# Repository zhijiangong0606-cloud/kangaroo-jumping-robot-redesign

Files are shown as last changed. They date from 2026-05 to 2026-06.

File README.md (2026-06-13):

# Kangaroo-Inspired Jumping Robot Redesign

This repository contains a mechanical redesign package for a kangaroo-inspired jumping robot course project.

The design uses a motor-preloaded elastic jumping architecture:

1. A DC gear motor slowly winds a drum.
2. The winding drum stretches an elastic tendon.
3. A latch holds the crouched energy-storage state.
4. A servo releases the latch.
5. The elastic tendon rapidly drives a 1-DOF closed-chain hind-leg mechanism.
6. An adjustable tail rod and tail mass improve pitch stability.

## Highlights

- Verified 1-DOF planar closed-chain hind-leg mechanism
- Motor preload and latch-release energy storage module
- SolidWorks 2026 native part files and completed layout assembly
- Mechanism animation GIF/WebP
- Engineering render images, DXF files, BOM, dimensions, and validation plan

## Final Deliverables (latest)

- **`袋鼠仿生弹跳机器人_设计任务书与说明书.md`** — course design task & specification document (12 sections, Chinese). Primary submission.
- **`solidworks_basic_model/kangaroo_overleap_bioinspired_v1/`** — final trustworthy 3D SolidWorks assembly:
  - `Kangaroo_Overleap_BioInspired_Assembly.SLDASM` — main assembly (16 native parts, 31 instances)
  - `parts/` — 16 native `.SLDPRT` files
  - `model_readme.md` — how the model was built and how to verify it
  - `parts_list.csv` — model parts list
  - `final_render.png` / `verify_multiview.png` — render + 4-view verification
  - `assembly_export.STL` — merged whole-assembly STL
  - `solve_mechanism.py` + `mechanism_pose.json` — geometry solver (all link-length constraints met to machine precision)

The new assembly is **geometry-solved first, then modeled**: every joint physically connects (shared M3 axles), the chain is a real closed loop, and the export bounding box is X≈417 × Y≈231 × Z≈52 mm — the 52 mm depth confirms it is a true 3D body, not a flat plate.

## Other Files

- `袋鼠仿生弹跳机器人_完整重设计报告.md` - full Chinese design report
- `README_交付说明.md` - Chinese delivery guide
- `solidworks_basic_model/mechanism_motion_animation.gif` - mechanism principle animation
- `solidworks_basic_model/mechanism_animation_keyframes_clean.png` - key-frame sheet
- `manufacturing_package/` - buildability-improved DXF files and fabrication checklist
- `external_references/overleap/` - Overleap open-source jumping leg (MIT), used as a CAD/assembly reference
- `MODEL_OPERABILITY_AUDIT.md` - CAD/model operability audit and improvement notes
- `BOM_redesigned_kangaroo_robot.csv` - bill of materials
- `verified_design_dimensions.csv` - verified design dimensions

## Historical Models (superseded, kept for reference only)

The earlier flat-looking assemblies are **not** the final deliverable. They had links that did not satisfy the closed-chain length constraints, a foot placed above the body, and no shared pivot axles, so parts appeared to float:

- `solidworks_basic_model/KangarooRobot_completed_engineering_layout.SLDASM`
- `solidworks_basic_model/KangarooRobot_TRUE_3D_assembly.SLDASM`
- `solidworks_basic_model/KangarooRobot_TRUE_3D_FIXED_assembly.SLDASM`

## Core Dimensions

| Item | Value |
|---|---:|
| H0-H1 | 100 mm |
| H0-H2 | 134 mm |
| L1 H1-A | 40 mm |
| L2 A-B | 120 mm |
| L3 H0-B | 100 mm |
| L4 B-F | 140 mm |
| L5 H2-F | 180 mm |
| Tail rod | 180-220 mm adjustable |

## Mechanism Mobility

For the single-side planar linkage:

```text
M = 3(n - 1) - 2j = 3(6 - 1) - 2*7 = 1
```

This proves that the proposed single-side hind-leg mechanism is a determinate 1-DOF closed-chain mechanism.

## Recommended Electronics

- ESP32 DevKit
- 12 V DC gear motor
- TB6612FNG or BTS7960 motor driver
- MG90S or 20 g servo
- MPU6050 IMU
- Limit switches
- LM2596 buck converter
- 2S Li-ion/LiPo battery

## Notes

The SolidWorks model is a completed engineering layout model. Before fabrication, refine the parts with final motor mounting holes, servo mounting holes, bearing seats, fillets, lightening holes, and detailed latch geometry.

For fabrication-oriented files, use the new `manufacturing_package/` folder. It adds manufacturing DXFs with lightening holes, M3 pivot references, bearing reference circles, tendon anchor holes, motor/servo mounting references, and an assembly checklist.

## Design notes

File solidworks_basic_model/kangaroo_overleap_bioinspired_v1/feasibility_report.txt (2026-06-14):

================================================================
(A) TRANSMISSION-ANGLE / DEAD-POINT CHECK
================================================================
  solvable crank range: theta in [-180.0, 180.0] deg
  min transmission angle at B (L2-L3 dyad): 29.9 deg
  min transmission angle at F (L4-L5 dyad): 85.1 deg
  threshold for good transmission: >= 40 deg
  VERDICT B-dyad: RISK - near dead point
  VERDICT F-dyad: OK

================================================================
(B) ENERGY-BUDGET SELF-CONSISTENCY
================================================================
  preload 30 mm: E=0.405 J  F_spring=27.0 N  est height=4.1 cm
  preload 40 mm: E=0.720 J  F_spring=36.0 N  est height=7.3 cm
  preload 45 mm: E=0.911 J  F_spring=40.5 N  est height=9.3 cm

  drum r=12 mm: winding torque needed = 0.486 N.m (= 5.0 kg.cm)
  drum r=18 mm: winding torque needed = 0.729 N.m (= 7.4 kg.cm)
  ref: 37D 6V gearmotor stall ~ 1.2-2.5 N.m (geared) -> ample for slow wind
  NOTE: spring force 40 N at full preload is the real structural load

================================================================
(C) FOOT-FORCE TRANSMISSION (release pose)
================================================================
  at mid-stroke theta=0.0:
    crank torque from tendon (max) = 1.620 N.m
    foot vertical travel rate = 0.0022 m/rad
    -> peak vertical foot force ~ 724.8 N
    weight to lift m*g = 4.41 N
    static force margin = 164.2x
    (>1 needed to launch; high ratio = brief impulse, good)

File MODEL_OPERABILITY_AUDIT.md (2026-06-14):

# Model Operability Audit

This audit records the current state of the CAD model and the changes made to improve buildability.

## Current SolidWorks Model Status

> **v7 update (physics-driven fixes):** a mechanics feasibility audit
> (`feasibility_audit.py`) found the old linkage gave the foot almost **no vertical
> push stroke** (2.2 mm of vertical vs 92 mm of horizontal scrub) — it could not
> have jumped regardless of spring energy. The mechanism was re-optimized
> (`optimize_mechanism.py`, topology unchanged) to **34.6 mm vertical foot travel**
> with a **60° minimum transmission angle** and zero interference over the working
> stroke. The latch was given a **14° self-locking tooth** so an MG90S servo can
> release it (~1 kg·cm vs the 3.7 kg·cm the old square tooth needed), the side
> plates were lightened (~27%), and a battery counter-mass + foot pads were added.
> Full assembly: 42 components, 29 concentric mates, solid STL.

Main assembly:

- `solidworks_basic_model/kangaroo_overleap_bioinspired_v1/Kangaroo_Overleap_BioInspired_Assembly.SLDASM`

The assembly is suitable for:

- explaining the mechanism architecture
- showing module placement
- demonstrating the relation between motor preload, latch release, elastic tendon, tail stabilizer, and closed-chain hind leg
- visual presentation and course reporting

Status after v6 functional-part pass:

- link parts now carry real hole pitches, lightening cuts, and bearing reference circles
- latch/pawl is now a functional solid with a defined catch face, not a block placeholder
- drum, foot, and standoff parts are modeled as buildable solids
- motor and servo remain envelope references pending final purchased-part dimensions
- geometry checked programmatically: parts mesh correctly, 27 concentric mates verified, set is printable
- a full SolidWorks dynamic mate set for motion simulation is still outstanding

## Practical Issues Found

| Issue | Impact | Fix / Mitigation |
|---|---|---|
| Simplified link geometry | Buildable, but not optimized for weight or bearings | Added manufacturing DXF with lightening holes and bearing reference circles |
| Placeholder motor and servo | Actual purchased parts may not match | Added adjustable mounting reference holes and noted final resizing requirement |
| Placeholder latch | Cannot be fabricated directly | RESOLVED v6: latch/pawl modeled as functional solid with defined catch face; final tuning after servo horn selected |
| No detailed washers/spacers in early model | Links may rub during physical assembly | Added spacer part and manufacturing checklist |
| Elastic tendon path is conceptual | May rub or over-stretch | Added tendon anchor holes and hook points in manufacturing DXF |
| Tail module was only visual | Needs parameter test | Added tail mass placeholder and 0/15/30 g validation plan |

## New Buildability Package

New folder:

- `manufacturing_package/`

Files:

- `body_side_plate_manufacturing_v2.dxf`
- `links_manufacturing_v2.dxf`
- `manufacturing_checklist.csv`
- `README_manufacturing_package_v2.md`

These files are intended for laser cutting, 2D CAD cleanup, or importing into SolidWorks as sketches.

## Recommended Next CAD Step

If more SolidWorks refinement is needed, do it in this order:

1. Import `body_side_plate_manufacturing_v2.dxf` into SolidWorks.
2. Rebuild the body plate as an editable sketch.
3. Import `links_manufacturing_v2.dxf`.
4. Rebuild each link as an editable part.
5. Add concentric mates at H0/H1/H2/A/B/F/T.
6. Drive the H1 crank angle and check for interference.
7. Replace placeholder motor, servo, and latch with actual purchased components.

## Minimum Fabrication Advice

- Use M3 bolts for all pivots.
- Add washers between every moving layer.
- Keep at least 0.5 mm side clearance per moving link.
- Test by hand before adding elastic preload.
- Start preload at 20 mm and increase gradually.
- Add a hard stop to prevent the motor from over-winding the elastic tendon.

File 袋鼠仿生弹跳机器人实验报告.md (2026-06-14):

# 袋鼠仿生弹跳机器人设计实验报告

## 一、实验目的

本实验以袋鼠的后肢弹跳为原型，设计一台单自由度的仿生弹跳机器人，并在 SolidWorks 中完成三维建模、装配与运动检查。具体要达到以下几点：

1. 把袋鼠后肢的"储能—释放—蹬伸"这一套动作，抽象成一个可以用平面连杆机构实现的运动方案；
2. 用解析方法把机构的杆长和铰点定下来，保证足端在一个工作行程里有足够的竖直行程，能够真正把弹性能转成起跳；
3. 在三维软件里把每个零件按真实厚度建出来，按解算坐标装配，验证关节确实连在一起、运动过程中不发生干涉；
4. 研究袋鼠尾巴在运动中的真实作用，并据此把尾部做成一个合理、可动、能配合主运动的结构；
5. 对整机做一次力学可行性核算，估算它在给定弹性预紧下大概能跳多高。

## 二、设计对象与生物原型

袋鼠是已知陆地动物里弹跳效率最高的一类。它的后肢在落地时把动能存进跟腱这类弹性组织里，起跳时再释放出来，所以连续跳跃几乎不额外耗能。我们要复现的就是这个"弹性储能 + 一次性释放"的机理，而不是简单地用电机直接驱动腿往下蹬。

机器人主体由一对侧板组成机架，两块侧板之间用立柱撑开，后肢机构夹在中间。腿部用一套六杆闭链来模拟股骨、胫骨、跖骨的折叠与展开。能量由一个减速电机通过绕线轮缓慢收紧弹性肌腱来储存，蹲伏到位后由一个棘爪锁住，需要起跳时舵机拨动棘爪解锁，弹性能瞬间释放、驱动腿蹬地。尾巴单独铰接在机架后方，可以摆动。

## 三、袋鼠尾部作用的调查

设计尾部之前，先查阅了袋鼠运动中尾巴作用的研究资料。结论是袋鼠尾巴在不同步态下扮演两种完全不同的力学角色：

**慢速行走时，尾巴是"第五条腿"。** 袋鼠低速移动时用的是五足步态：前肢和尾巴先着地支撑，后肢再向前迈。这时尾巴主动压地、向后蹬，提供的推进力大致相当于前后四肢之和（O'Connor 等人 2014 年发表在 Biology Letters 上的测力研究给出了这个量级）。也就是说，慢速时尾巴是一个落地承力、主动做功的支撑腿。

**跳跃时，尾巴是抬起的动态配重。** 进入双足跳跃后，尾巴离开地面，在空中相对身体反向摆动，用来平衡后肢蹬地和落地时产生的俯仰力矩，让躯干姿态保持稳定。这时尾巴不接触地面，作用是配重和姿态控制。

对照这两个角色再看原来的模型，问题很明显：原来的尾巴是用一根销钉死死固定在机架上的刚性直杆，尾端的 Y 坐标大约在 −109 mm，比足端所在的地面线（约 −90.5 mm）还低了将近 19 mm。这样一根扎进地里、又动不了的杆子，既做不了慢速时的落地支撑（它本来就一直顶在地下、还会卡住腿的运动），也做不了跳跃时的抬起配重（它根本不能动）。所以尾部需要重新设计成一个能在两种姿态之间切换的可动结构。

## 四、机构方案与运动学求解

### 4.1 机构拓扑

后肢采用单自由度平面六杆闭链。机架上有三个固定铰点，记作 H0、H1、H2。输入曲柄 L1 绕 H1 转动，依次通过连杆 L2、大腿摇杆 L3（绕 H0）、小腿 L4、后摇杆 L5（绕 H2）把运动传到足端 F，足端再延伸出一段足杆触地。整个机构只有一个自由度，由曲柄转角 θ 单独决定所有杆件的位姿，符合课程对机构拓扑的要求。

### 4.2 杆长与铰点的确定

机构的尺寸不是随便定的，而是先列出闭链的杆长约束，再用圆-圆交点法求解。给定曲柄角后，A 点位置由 H1 和 L1 确定；B 点必须同时落在以 A 为圆心、L2 为半径的圆，以及以 H0 为圆心、L3 为半径的圆上，两圆相交即解出 B；F 点同理由 L4、L5 两个约束圆相交解出。求解脚本 `solve_mechanism.py` 把五个杆长约束全部满足到 1e-13 mm 的机器精度。

最终确定的几何参数如下（坐标相对 H0）：

| 参数 | 数值 | 说明 |
|---|---|---|
| H0–H1 机架孔距 | 114.6 mm | H1 位于 (−94.8, 64.4) |
| H0–H2 机架孔距 | 139.6 mm | H2 位于 (134.3, 38.0) |
| L1 曲柄 H1–A | 59.0 mm | 输入曲柄 |
| L2 连杆 A–B | 108.9 mm | 传递输入 |
| L3 大腿摇杆 H0–B | 88.2 mm | 对应股骨段 |
| L4 小腿 B–F | 100.3 mm | 对应胫骨/跖骨段 |
| L5 后摇杆 H2–F | 160.6 mm | 约束足端轨迹 |
| 足杆 F–足端 | 80 mm | 足端延伸 |
| 工作行程 | θ = −180° → −96° | 蹲伏到发射 |

### 4.3 为什么是这组尺寸

这组尺寸是优化得到的，不是初版尺寸。最早一版的杆长虽然也能装配，但曲柄转一整圈，足端的竖直行程只有 2.2 mm，水平方向却划过 92 mm——这等于让机器人"贴地横划"，弹簧存再多能也做不了起跳的功。

在保持六杆闭链拓扑、分层和销轴连接方式都不变的前提下，用 `optimize_mechanism.py` 重新搜索杆长和机架铰点位置，目标是把足端竖直行程做大、同时让传动角全程远离死点。优化后的结果是：

- 足端竖直行程从 2.2 mm 提高到 **34.6 mm**；
- 最小传动角从 29.9°（接近死点、危险）提高到 **60.1°**（安全，门槛是 40°）。

这组优化后的几何此后被冻结，作为所有后续建模的基准，不再改动。

## 五、双模式仿生尾的设计

根据第三节的调查结论，尾巴被重新设计成一个能在两种姿态间切换的可动结构。

把尾巴根部的铰点 T 设在机架坐标 (−95, 2)，这里改用一根贯穿两块侧板的全宽 M3×80 轴作为转动铰，尾杆的根孔套在这根轴上，可以绕 T 自由转动。为了把摆动限制在合理范围，尾杆根部开了一条以 T 为圆心的圆弧限位槽（半径 28 mm，本地张角 ±18.25°，总摆幅 36.5°）；机架在 (−122.735, −1.84) 处——也就是离 T 正好 28 mm 的地方——再加一根全宽 M3×80 止挡销，穿过这条弧槽。弧槽的两端就成了两个硬性限位：

- **下限位**（尾轴角 −153.87°）：尾端落到约 (−283.6, −90.4)，正好接近足端地面线，对应慢速时尾巴落地支撑的"第五条腿"姿态；
- **上限位**（尾轴角 −190.37°）：尾端抬到约 (−301.6, +39.8)，离地足够高，对应跳跃时抬起的空中配重姿态。

装配时把尾巴静态停在两限位之间的中位（−172.12°）。尾杆截面高度从原来的 22 mm 提到 26 mm，让弧槽两侧各留约 3.7 mm 的连接料来承受止挡载荷。由于尾巴不属于第四节里那条六杆闭链，这个改动不影响主机构的几何，是安全的。

尾端装一个 Ø44×16 的圆盘配重，用一根 M3 销把配重盘和尾杆连在一起，配重质量在 0–30 g 间可调，用来微调跳跃时的俯仰平衡。

在运动动画里，尾巴的摆角与曲柄相位做线性联动：蓄能位（θ = −180°）尾巴下垂支撑，起跳位（θ = −96°）尾巴上扬配重，配重盘和尾尖销随尾端一起跟随。这样尾部就和主运动配合起来，复现了袋鼠"慢速落地支撑、起跳抬起配重"的双模式行为。

## 六、三维建模与装配

### 6.1 零件建模

整机共 31 个零件实例，对应 16 个唯一零件，全部是在 SolidWorks 里用草图加拉伸生成的原生实体零件，不是网格导入的占位体。建模遵循几个原则：

- **原点定在铰点上。** 每个连杆零件的局部原点放在它的第一个铰孔，杆体沿 +X 方向伸到第二个铰孔。装配时按解算坐标平移再绕 Z 旋转放置，铰孔自然就对齐了，关节是真正连在一起的。
- **真实三维厚度。** 所有零件用 Front 平面草图加中面拉伸生成，关于自身中面对称。左右后肢镜像分布在 z = ±15 mm，两块侧板在 z = ±24 mm。导出整机 STL 的包围盒在 Z 方向有几十毫米的厚度，证明这是立体结构而不是一块平板。
- **共享轴贯穿。** M3 轴穿过 H0/H1/H2/A/B/F/T 各铰点，把左右后肢连成一体；立柱把两块侧板撑开并固定。

### 6.2 标准机械零件

在机构几何冻结的前提下，关节处用上了标准机械零件，让设计从"塑料板直接套销"升级到接近真实可装配的水平：

- **固定铰 H0/H1/H2**：装 GB/T 276 深沟球轴承 623（d3 D10 B4），共 6 个。连杆该端的孔扩成 Ø10 轴承座，轴承内圈套在固定销上、外圈随连杆转，连杆在滚动体上转动，避免塑料对销干磨。轴承宽 4 mm 与连杆齐平，不增加 Z 向尺寸。
- **运动铰 A/B/F**：每个连杆孔压入一个滑动衬套（OD6 内径 3.2 长 4，含油轴承），共 16 个，共享销穿过全部衬套。
- **键连接**：绕线轮内孔做 GB/T 1096 平键槽，电机 Ø6 输出轴铣对应键槽，用一个 2×2×8 平键传递卷扬扭矩，替代原来 Ø6.2 间隙孔的摩擦传动。
- **轴向定位**：运动铰销两端各车一道挡圈槽，配 GB/T 896 轴用 E 形挡圈。运动铰不夹紧（夹紧会锁死连杆），连杆靠衬套自由转、挡圈只做轴向限位。
- **紧固件**：固定铰和四个角立柱用 GB/T 70.1 内六角螺钉 + GB/T 93 弹簧垫圈 + GB/T 97 平垫圈 + GB/T 6170 六角螺母的完整栈。

零件清单见随附的 `parts_list.csv` 和 `BOM_redesigned_kangaroo_robot.csv`。

### 6.3 装配流程

装配分两步走，这是为了避开 COM 调用过载导致 SolidWorks 崩溃的问题：

1. `CreatePrintableAssembly` 只负责把所有零件按解算坐标放进装配体并保存，不加配合；
2. `AddMatesLite` 再单独跑一遍，给各铰点加同心配合。它的做法是一次性把装配里所有沿 Z 的圆柱面缓存下来（约一百多个），再按铰点从缓存里匹配销和孔，这样 COM 调用量比逐铰点遍历全部零件面要小约 7 倍，并且逐铰点保存以防崩溃丢进度。

### 6.4 能量与驱动模块

由于 70 mm 长的电机筒身塞不进 64 mm 宽的侧板笼内、还会撞到曲柄，整组驱动（电机 + 绕线轮 + 棘爪 + 舵机）被移到 +Z 侧板外侧，用一块支撑板（WinchBracket）和三根立柱（WinchPost）连回侧板，完全避开笼内的腿机构。代价是机器向一侧悬出，为此在 −Z 侧加了一个电池 + 控制器配重包来抵消侧向倾覆力矩。

释放棘爪做成 L 形杠杆，钩唇带 14° 后仰自锁齿形：满预紧时齿载反力自锁、锁得住，舵机解锁只需约 1 kg·cm 的力矩，MG90S 舵机能够胜任。

## 七、验证

### 7.1 配合与连接

清理重建后跑 `AddMatesLite`，得到 **34 个同心配合、0 个失败**。`MateCount` 复核了这个数字（它直接遍历配合特征树，不会被缓存骗）。其中尾根 T 点 holes=3 ok=3，说明尾杆根孔的铰接成功建立。

需要说明的是，装配脚本内部自带的一个按坐标选面加配合的函数是无效的——它的坐标拾取打不到埋在笼子内部的圆柱面，所以真正的配合一律由 `AddMatesLite` 按面几何匹配来建。之前一度看到的"40 个配合"是一个旧的残留文件，干净重建的正确数字是 34。

`ConnAudit` 审核确认所有含实体的零件都至少和另一个零件有实体接触，没有凌空悬空的零件，打印出来可以物理装配。

### 7.2 尺寸与就位核对

用 `BoxProbe` 实测各零件的包围盒：两根全宽轴分别在 T 和 TS 处、Z 方向从 −40 到 40 贯穿两块侧板；尾杆在中心面附近（Z 从 −2 到 2）；配重盘叠在 +Z 面一侧（Z 从 2 到 18）。键的位置、轴承座、衬套、挡圈槽的包围盒也逐一核对，都落在设计位置上。

### 7.3 干涉检查

`sweep_interference.py` 在整个工作行程 θ ∈ [−180°, −96°] 内扫描，连杆与连杆之间的重叠为 0，立柱干涉为 0，各 Z 分层之间没有连杆相撞。

### 7.4 运动动画

`AnimateAssembly` 驱动曲柄走完工作行程，输出四个视角（前视、等轴测、右视、斜二测）的动画，尾巴的下垂—上扬摆动正常（tail = 3/3），27 个运动硬件件随腿联动跟随。对比前视的蹲伏帧和起跳帧，尾巴确实在两种姿态间真实摆动。

动画的四视角生成过程中修掉了一个 bug：原来四张动图实际上是同一个相机角度，原因是切换命名视图的接口在脚本环境下用 −1 参数会静默失效。改成传标准视图的整数 ID 并在切换后重绘，四个视角才真正不同（同一帧的四视角图像哈希全部不同可证）。

## 八、力学可行性与跳高估算

对"打印出来能不能真跳起来"做了一次力学核算（`feasibility_audit.py`）：

- **传动**：起跳位附近曲柄从肌腱得到的力矩约 1.62 N·m，足端竖直方向的峰值蹬地力约 725 N，而整机重量约 4.4 N，静力裕度很大，足够把机器人弹离地面。
- **结构载荷**：满预紧时弹簧力约 40 N，是结构上真正要承受的载荷。按这个载荷核算，棘爪钩唇接触应力约 2.1 MPa、M3 钢销剪切约 7.9 MPa，都在安全范围内。
- **质量**：按实体体积预算，整机约 674 g（0.67 kg），其中侧板最重，已经通过 3 mm 板厚加减重孔阵列减重。新增的金属标准件（轴承、衬套、键、挡圈、垫圈、螺母）净增约 43 g，这部分增重换来了真实的可装配性和传动可靠性。

按真实质量 0.67 kg、弹簧刚度 k≈900 N/m、能量转换效率约 45%、发射角 35° 估算，不同弹性预紧量下的跳高如下：

| 预紧量 (mm) | 弹性能 (J) | 估算跳高 (cm) | 估算射程 (cm) |
|---:|---:|---:|---:|
| 20 | 0.180 | 1.31 | 2.46 |
| 30 | 0.405 | 2.95 | 5.54 |
| 40 | 0.720 | 5.24 | 9.85 |
| 45 | 0.911 | 6.63 | 12.47 |

在 40 mm 预紧下估算跳高约 5 cm，落在 2–9 cm 的设计指标区间内。建议实测时预紧量先小后大、逐步加载。

## 九、简化说明

为了把重点放在机构与装配的正确性上，模型里有几处做了合理简化，这些简化不影响三维装配的可信度和机构拓扑/配合的正确性，属于到量产细化之间的正常后续工作：

- 电机和舵机用外形包络表示，但已经带了真实的输出轴和安装翼接口，购得实物后按实际安装孔微调即可；
- 弹性肌腱用一根直杆代表它的工作长度，实物为拉簧或橡皮筋束；
- 电机输出轴与绕线轮之间的键连接已经按 GB/T 1096 建出键槽和平键。

## 十、结论

本实验完成了一台单自由度袋鼠仿生弹跳机器人的三维设计：

1. 用六杆闭链复现了袋鼠后肢的折叠—蹬伸动作，杆长和铰点经过优化，足端竖直行程做到 34.6 mm、最小传动角 60.1°，具备做功起跳的条件；
2. 调查了袋鼠尾巴慢速落地支撑、跳跃抬起配重的双重作用，据此把尾部设计成根部铰接、带圆弧限位槽的双模式可动结构，并让它和主运动联动；
3. 在 SolidWorks 中完成了 31 个零件实例的原生实体建模与装配，加上了轴承、衬套、键、挡圈、紧固件等标准机械零件；
4. 通过配合数（34 个 0 失败）、连接审核（无悬空件）、干涉扫描（工作行程零干涉）、包围盒核对和四视角运动动画，验证了装配的正确性；
5. 力学核算表明整机约 0.67 kg，在 40 mm 弹性预紧下估算可跳约 5 cm，满足设计指标。

随报告附上完整的 SolidWorks 装配体与全部零件、四视角运动动画、渲染图、零件清单和分析数据，可在 SolidWorks 中打开复核。

## 附录：随附文件清单

- `模型/Kangaroo_Overleap_BioInspired_Assembly.SLDASM` —— 主装配体
- `模型/parts/` —— 全部 SolidWorks 零件
- `模型/assembly_export.STL` —— 整机合并 STL
- `动图/assembly_motion_grid.gif` —— 四视角运动总览
- `动图/assembly_motion_front/iso/right/dimetric.gif` —— 各单视角运动
- `渲染图/` —— 等轴测、前视、右视、斜二测着色渲染
- `数据/parts_list.csv`、`BOM_redesigned_kangaroo_robot.csv` —— 零件清单
- `数据/design_dimensions.csv` —— 机构尺寸表
- `数据/estimated_jump_results.csv`、`feasibility_report.txt` —— 跳高估算与力学核算
- `模型/model_readme.md` —— 建模与复现说明

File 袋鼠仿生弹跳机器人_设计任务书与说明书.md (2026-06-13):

# 袋鼠仿生弹跳机器人 设计任务书 / 设计说明书

> 机械设计课程项目 · 重设计版本
> 单位：__________  专业：__________  班级：__________  姓名：__________  学号：__________  指导教师：__________  日期：__________

---

## 0. 文档说明

本文件是袋鼠仿生弹跳机器人的课程提交材料，同时充当**设计任务书**（规定要做什么、达到什么指标）与**设计说明书**（说明怎么做、为什么这么做）。

本次为**重设计版本**。原方案被评价为“机构设计不足，无法构成机构，没有很好展示袋鼠运动仿生”。重设计的核心思路是：**从“外形像袋鼠”转为“运动机理像袋鼠”**——以确定的一自由度闭链机构、弹性储能、锁止瞬时释放、尾部配重平衡来对应袋鼠的真实跳跃机制，并给出可验证的自由度计算、可制造结构和可信的三维装配。

配套三维模型见：
`solidworks_basic_model/kangaroo_overleap_bioinspired_v1/Kangaroo_Overleap_BioInspired_Assembly.SLDASM`

---

## 1. 项目名称

**袋鼠仿生弹跳机器人设计**（Kangaroo Bio-Inspired Jumping Robot）

英文名：Kangaroo-Inspired Elastic-Energy Jumping Robot
项目代号：kangaroo_overleap_bioinspired_v1

---

## 2. 设计背景与意义

### 2.1 背景

袋鼠是自然界中最高效的跳跃动物之一。其运动有几个突出特征：

- **后肢同步蹬伸**：左右后肢几乎同时发力，避免侧向翻转。
- **肌腱弹性储能**：跟腱在落地压缩时储存能量，蹬伸时释放，使连续跳跃的代谢能耗几乎不随速度上升而增加。
- **多关节协同**：髋、膝、踝在一次蹬伸中按固定规律联动。
- **尾部平衡**：粗大的尾巴在腾空和落地时提供俯仰惯量与配重，稳定姿态，慢速时还作为“第五条腿”形成三点支撑。

### 2.2 工程意义

直接用小型电机驱动跳跃存在瓶颈：起跳瞬间需要很高的功率，而小型直流电机的瞬时扭矩和响应往往不足。袋鼠“慢速储能、瞬时释放”的策略正好规避了这一点。把这一机理工程化，可以：

- 用低功率电机实现高瞬时输出的跳跃；
- 用确定的闭链机构保证“一个输入 → 多关节协调蹬伸”，使机构可分析、可重复；
- 用尾部配重改善起跳与落地姿态稳定性。

### 2.3 对原方案问题的直接回应

| 老师指出的问题 | 本方案的回应 |
|---|---|
| 机构设计不足 | 给出明确的六杆闭链拓扑、构件表与铰点表 |
| 无法构成机构 | 给出自由度计算 M=1，并用圆-圆交点法解出真实可装配位姿 |
| 没有展示袋鼠仿生 | 用弹性储能 + 锁止释放 + 尾部配重对应袋鼠跳跃机理，而非仅做外形 |

---

## 3. 设计目标与技术指标

### 3.1 功能目标

1. 建立一个**确定运动的机构**（一自由度闭链后肢），而非静态造型。
2. 完成**可信的三维建模与装配**（SolidWorks，可打开检查、无明显悬空、部件连接明确）。
3. 完成**可制造结构设计**（材料、连接、紧固、BOM、加工方式）。
4. 完成**电机预紧 / 锁止释放**的储能-释放方案。
5. 完成**尾部仿生稳定**设计（可调尾杆 + 尾端配重）。

### 3.2 量化技术指标（课程演示级）

| 指标 | 目标值 | 说明 |
|---|---|---|
| 整机质量 | ≤ 0.5 kg | 含电池、电机、舵机 |
| 后肢自由度 | 单侧 1 | 闭链，确定运动 |
| 弹性预紧量 | 20–45 mm 可调 | 分级测试 |
| 预估跳高 | 2–9 cm | 初设估算，见第 6 节 |
| 尾端配重 | 0–30 g 可调 | 姿态对比实验用 |
| 控制电压 | 6–12 V | 减速电机 + 舵机 |
| 重复跳跃 | 可循环预紧-释放 | 状态机控制 |

> 注：跳高/跳远为初步能量估算，非实测；答辩前应以实测均值±标准差替换（见第 11 节）。

---

## 4. 仿生分析

### 4.1 袋鼠后肢

袋鼠后肢相对人类有明显的“远端长、近端短”比例：股段相对短，小腿（胫骨）与跖足相对长。长的远端杆件在蹬伸末段提供更大的足端线速度，有利于弹跳。

**本设计对应**：大腿摇杆 L3 = 100 mm，小腿 L4 = 140 mm，足部延伸约 80 mm，体现“远端较长”的弹跳动物形态。

### 4.2 跟腱 / 肌腱弹性储能

袋鼠跟腱在落地相被拉伸储能，在蹬伸相回弹释放，相当于一个并联在关节上的弹性元件。这使得袋鼠在一定速度区间内连续跳跃几乎不额外增加代谢能耗。

**本设计对应**：用拉簧 / 橡皮筋束作为“弹性肌腱”，由电机经绕线轮缓慢拉伸储能，释放时驱动闭链快速伸展。电机只承担**慢速能量输入**，不承担起跳瞬时功率。

### 4.3 尾部平衡作用

袋鼠尾巴质量大、力臂长：腾空相提供俯仰惯量调节身体姿态，落地相缓冲并配重；慢速移动时尾巴着地与两后肢形成稳定的三点支撑。

**本设计对应**：可调尾杆（180–220 mm）+ 尾端配重（0–30 g），向机身后下方伸出，与前下方伸出的足端形成姿态平衡，改善起跳/落地俯仰稳定性。

### 4.4 本项目对应结构小结

| 袋鼠运动特征 | 本设计对应结构 | 设计意义 |
|---|---|---|
| 后肢同步跳跃 | 左右腿经 M3 横轴同步释放 | 避免单侧先释放导致侧翻 |
| 肌腱储能回弹 | 弹性肌腱 + 绕线轮 | 降低电机瞬时功率需求 |
| 髋/膝/踝协同伸展 | 六杆闭链后肢 | 一个输入实现多关节联动 |
| 尾部辅助平衡 | 可调尾杆 + 尾端配重 | 改善俯仰稳定性 |
| 着地后再储能 | 电机重新收线预紧 | 形成可重复跳跃循环 |

---

## 5. 总体方案

机器人由七大部分组成：

1. **机身（机架）**：两块平行侧板，承载所有固定铰点 H0/H1/H2 与尾部铰点 T，以及电机/舵机/锁扣安装位。
2. **后肢闭链机构**：左右各一套平面六杆闭链（详见第 6 节），是运动核心。
3. **弹性肌腱**：拉簧 / 橡皮筋束，储存弹性势能。
4. **电机 + 绕线轮**：减速电机慢速收线，把旋转运动转为肌腱拉伸（能量输入）。
5. **锁扣 + 舵机释放**：锁扣（棘爪）保持蹲伏储能状态；微型舵机拨开锁扣实现瞬时释放。
6. **尾杆 + 配重**：被动可调，提供俯仰稳定与三点支撑。
7. **控制系统**：开发板 + 电机驱动 + 舵机 + 限位/姿态传感器。

### 5.1 工作循环

```mermaid
flowchart LR
    A["待机"] --> B["电机收线预紧<br/>拉伸弹性肌腱"]
    B --> C{"限位开关<br/>预紧到位?"}
    C -- 否 --> B
    C -- 是 --> D["锁扣保持<br/>电机停止"]
    D --> E["舵机拨开锁扣"]
    E --> F["肌腱瞬时回弹<br/>闭链快速伸展"]
    F --> G["足端蹬地起跳<br/>腾空（尾部稳定）"]
    G --> H["落地延时"]
    H --> B
```

文字描述：电机带动绕线轮收线 → 弹性件被拉伸、后肢蹲伏 → 锁扣锁住储能位置、电机停转 → 舵机拨开锁扣 → 弹性件瞬时回弹驱动闭链伸展 → 足端向后下方蹬地、机器人起跳 → 腾空阶段尾杆提供俯仰惯量 → 落地后重新预紧，形成循环。

---

## 6. 机构设计

### 6.1 单侧后肢机构拓扑

单侧后肢为**平面六杆闭链机构**：

| 构件 | 名称 | 铰点 | 杆长 |
|---|---|---|---:|
| L0 | 机架 | 含固定铰 H0、H1、H2 | — |
| L1 | 输入曲柄 | H1–A | 40 mm |
| L2 | 连杆 | A–B | 120 mm |
| L3 | 大腿摇杆 | H0–B | 100 mm |
| L4 | 小腿杆 | B–F | 140 mm |
| L5 | 后摇杆 | H2–F | 180 mm |
| — | 足部 | 由 F 向前下延伸 | ≈80 mm |

机架固定孔距：H0–H1 = 100 mm，H0–H2 = 134 mm。
足部为触地执行端，刚接在 L4 末端的 F 点。

### 6.2 自由度计算

按平面低副机构（Grübler 公式）计算：

```text
M = 3(n - 1) - 2·j
n = 6   （机架 L0 + 5 个活动构件 L1~L5）
j = 7   （转动副：H0, H1, H2, A, B, F, 以及闭链中第 7 个低副）
M = 3 × (6 - 1) - 2 × 7 = 15 - 14 = 1
```

**结论：M = 1，单侧后肢是确定运动的一自由度闭链机构。** 即只要给定一个输入（曲柄 H1–A 的转角），整条腿的运动就完全确定。这直接回应了“无法构成机构”的问题。

### 6.3 关键尺寸表

| 项目 | 数值 |
|---|---:|
| H0–H1 机架孔距 | 100 mm |
| H0–H2 机架孔距 | 134 mm |
| L1 曲柄 H1–A | 40 mm |
| L2 连杆 A–B | 120 mm |
| L3 大腿摇杆 H0–B | 100 mm |
| L4 小腿 B–F | 140 mm |
| L5 后摇杆 H2–F | 180 mm |
| 足部延伸 | ≈80 mm |
| 尾杆长度 | 180–220 mm（可调） |
| 尾端配重 | 0–30 g（可调） |
| 侧板厚度 | 3–4 mm |
| 左右侧板间距 | ≈48 mm |
| 弹性预紧量 | 20–45 mm |
| 绕线轮半径 | 12–18 mm |

### 6.4 位姿解算与可装配性验证

本方案没有凭手感摆放连杆，而是**先解算几何再建模**。用圆-圆交点法：给定曲柄角 θ，先求 A，再由 |A–B|=120 与 |H0–B|=100 两圆交点求 B，再由 |B–F|=140 与 |H2–F|=180 两圆交点求 F。

选定曲柄角 **θ = -121°**（蹲伏储能姿态），解得各铰点坐标（单位 mm，机身坐标系，X 向前、Y 向上）：

| 点 | 坐标 (x, y) |
|---|---|
| H0 | (0.000, 0.000) |
| H1 | (-80.000, 60.000) |
| H2 | (120.000, 60.000) |
| A | (-100.602, 25.713) |
| B | (-53.339, -84.587) |
| F | (83.053, -116.167) |
| 足端 | (160.991, -134.213) |

**杆长约束校核**（计算值 vs 目标，误差到机器精度）：

| 约束 | 目标 | 计算值 | 误差 |
|---|---:|---:|---:|
| H1–A (L1) | 40 | 40.000 | 0 |
| A–B (L2) | 120 | 120.000 | <1e-13 |
| H0–B (L3) | 100 | 100.000 | 0 |
| B–F (L4) | 140 | 140.000 | 0 |
| H2–F (L5) | 180 | 180.000 | 0 |

五个杆长约束全部满足，足端落在机身下方约 134 mm，证明该位姿真实可装配、闭链真实闭合。解算脚本：`solidworks_basic_model/kangaroo_overleap_bioinspired_v1/solve_mechanism.py`，结果存于 `mechanism_pose.json`。

### 6.5 足端运动逻辑

随曲柄 H1–A 从蹲伏角向伸展角转动，闭链联动使大腿摇杆 L3 与后摇杆 L5 同时外摆，足端 F 沿一条向后下方的轨迹快速下压、蹬地，从而产生起跳推力。释放时弹性肌腱驱动曲柄快速转过这一区间，把储存的弹性势能转化为足端蹬地冲量。机构干涉检查与运动范围见第 11 节。

---

## 7. 驱动与控制方案

### 7.1 为什么不用电机直接驱动跳跃

起跳瞬间需要很高的功率，小型直流电机的瞬时扭矩与响应都不足。因此采用**慢速储能、瞬时释放**：电机只负责慢速把能量“充”进弹性件，真正的高功率输出由弹性件回弹完成。

### 7.2 驱动链组成

| 模块 | 选型建议 | 作用 |
|---|---|---|
| 减速电机 | 6–12 V 直流减速电机 | 慢速收线，能量输入 |
| 绕线轮 | r = 12–18 mm | 把电机旋转转为肌腱拉伸 |
| 弹性肌腱 | 拉簧 / 橡皮筋束 | 储存弹性势能 |
| 锁扣 / 棘爪 | PLA / 铝 | 保持蹲伏储能状态 |
| 释放舵机 | MG90S / 20 g 舵机 | 拨开锁扣实现瞬时释放 |
| 限位开关 | 微动开关 | 检测预紧到位，防过拉 |

### 7.3 控制系统

- **主控**：ESP32 DevKit（或 Arduino Nano）。
- **电机驱动**：TB6612FNG（小电流）或 BTS7960（大电流）。
- **姿态传感（可选）**：MPU6050 IMU，用于记录起跳/落地俯仰角，支撑尾重对比实验。
- **电源**：2S 锂电 + LM2596 降压，分别供主控逻辑与电机/舵机。

### 7.4 控制流程（状态机）

```text
待机 IDLE
  └─→ 预紧 PRELOAD：电机收线
        └─ 限位触发？ 否→继续收线；是→进入 LOCKED
  └─→ 锁定 LOCKED：锁扣保持，电机停止
        └─→ 释放 RELEASE：舵机拨开锁扣
              └─→ 起跳 JUMP：弹性件回弹，闭链伸展，足端蹬地
                    └─→ 落地延时 LAND_DELAY
                          └─→ 回到 PRELOAD（循环）
```

### 7.5 安全建议

- 预紧从 20 mm 开始，逐级增加，不要一上来拉到 45 mm。
- 机身上设机械硬限位，防止曲柄越位。
- 舵机释放前，人手远离腿部与弹性件。
- 电机收线端加限位开关或电流检测，避免过拉烧电机。

---

## 8. 尾部仿生设计

### 8.1 被动可调尾杆

尾杆为被动件（不主动驱动），通过铰点 T 接在机身后下方，向后下方伸出。长度 180–220 mm 可调，用于改变力臂。材料用碳杆 / 铝杆 / 打印杆。

### 8.2 尾端配重

尾端用螺母叠加实现 0–30 g 可调配重。配重越大、力臂越长，对机身俯仰的惯量与配平作用越强，但也增加整机质量。需要在“稳定性”与“质量”之间折中，由实验确定。

### 8.3 俯仰稳定实验设计

- **变量**：尾端配重 0 g / 15 g / 30 g。
- **测量**：用 IMU 或高速视频记录起跳瞬间与落地瞬间的机身俯仰角峰值。
- **判据**：俯仰角峰值越小、落地后回稳越快越好。
- **输出**：配重-俯仰角曲线，给出推荐配重。
- **预期**：适当配重显著降低起跳后“前倾/后仰”幅度，验证袋鼠尾部平衡仿生的有效性。

---

## 9. 材料与制造方案

### 9.1 推荐材料与工艺

| 部件 | 材料 | 工艺 |
|---|---|---|
| 机身侧板 | 3–4 mm 亚克力 / 碳板 / PLA | 激光切割 / 3D 打印 |
| 连杆 L1–L5 | 3 mm 亚克力 / 铝板 / PLA | 激光切割 / 3D 打印 / CNC |
| 足部 | PLA 主体 + 橡胶垫 | 3D 打印 + 粘贴橡胶 |
| 尾杆 | 碳杆 / 铝杆 / 打印杆 | 标准件 / 打印 |
| 尾端配重 | 钢螺母 | 标准件 |
| 关节销轴 | M3 螺栓 | 标准件 |
| 侧板立柱 | 铜柱 / PLA 垫柱 | 标准件 / 打印 |
| 弹性件 | 拉簧 / 橡皮筋束 | 标准件 |

### 9.2 关节与连接

- 所有铰点用 **M3 螺栓** + 垫片 + 尼龙锁紧螺母；条件允许可加 3×6×2.5 mm 微型轴承。
- 每个运动层之间加垫片，单侧留 ≥0.5 mm 间隙，避免连杆相互摩擦。
- 侧板间用 M3 铜柱 / 打印垫柱撑开，间距约 48 mm。
- 足部加橡胶垫，提高摩擦并缓冲落地。

### 9.3 BOM

详见 `BOM_redesigned_kangaroo_robot.csv`（项目根目录）与三维模型零件清单 `solidworks_basic_model/kangaroo_overleap_bioinspired_v1/parts_list.csv`。

### 9.4 装配最小建议

- 用手转动曲柄确认机构顺畅、无卡死，再装弹性件。
- 加硬限位防止电机过卷弹性件。
- 先低预紧（20 mm）试跳，逐步加大。

---

## 10. 建模方案

### 10.1 SolidWorks 建模内容

最终三维装配位于：
`solidworks_basic_model/kangaroo_overleap_bioinspired_v1/Kangaroo_Overleap_BioInspired_Assembly.SLDASM`

共 16 个唯一原生零件、31 个零件实例，全部为 SolidWorks 实体零件（非网格导入），在第 6.4 节解算的蹲伏储能位姿下装配。

### 10.2 零件清单（建模）

| 零件 | 实例数 | 角色 |
|---|---:|---|
| BodyPlate_3D | 2 | 机身侧板（六边形，含全部固定铰孔与模块安装孔） |
| L1_Crank_40 | 2 | 输入曲柄 H1–A |
| L2_Coupler_120 | 2 | 连杆 A–B |
| L3_Thigh_100 | 2 | 大腿摇杆 H0–B |
| L4_Shank_140 | 2 | 小腿 B–F（带减重孔） |
| L5_Rocker_180 | 2 | 后摇杆 H2–F |
| Foot_80 | 2 | 足部 / 触地端 |
| TailRod_210 | 1 | 尾杆 T–尾端 |
| TailMass | 1 | 尾端配重 |
| ElasticTendon_52 | 1 | 弹性肌腱（绕线轮→A） |
| Drum | 1 | 绕线轮 |
| Motor | 1 | 减速电机（外形包络） |
| Servo | 1 | 释放舵机（外形包络） |
| Latch | 1 | 锁扣 / 棘爪（外形包络） |
| M3_Axle_60 | 7 | 铰点销轴（贯穿左右） |
| Standoff_44 | 4 | 侧板立柱 |

### 10.3 装配关系

- 零件局部原点定义在第一个铰孔，杆体沿 +X 伸到第二个铰孔；装配时按解算坐标平移 + 绕 Z 旋转放置，铰孔自然对齐。
- 左右后肢镜像在 z = ±15 mm，两块侧板在 z = ±24 mm（间距约 48 mm）。
- 7 根 M3 轴穿过 H0/H1/H2/A/B/F/T 各铰点，把左右后肢连成一体；4 根立柱撑开并固定两块侧板。
- 导出整机 STL 的包围盒为 X≈417 × Y≈231 × **Z≈52 mm**，Z 向厚度证明是立体结构而非平板。

### 10.4 参考 Overleap 的结构组织方式

参考开源项目 **Overleap**（MIT 许可，`external_references/overleap`）的“侧板 + 腿 + 足 + 电机/轴/支架”模块化组织方式与装配图组织逻辑。Overleap 是真实可跳的低成本 3D 打印动态跳跃腿，采用准直驱执行器，其 CAD/装配质量可靠，适合作为三维建模与装配的参照。

### 10.5 本项目改型内容

在 Overleap 的结构逻辑之上做袋鼠仿生改型（而非直接复用其带传动腿）：

- 后肢用**一自由度六杆闭链**（Overleap 为准直驱带传动），保留课程要求的机构拓扑；
- 增加**弹性肌腱 + 绕线轮**（电机慢速储能）；
- 增加**舵机 + 锁扣**（蹲伏储能保持与瞬时释放）；
- 增加**袋鼠仿生尾杆 + 尾端配重**（俯仰平衡 / 三点支撑）。

> 改型解释：Overleap 用电机直驱关节实现跳跃，依赖较强的准直驱执行器；本课程项目受限于小型电机，改用“闭链 + 弹性储能 + 锁止释放”来获得高瞬时输出，并增加尾部以贴合袋鼠仿生主题。两者共享“侧板夹持多连杆 + 足端触地”的整体布局逻辑。

### 10.6 模型可信度说明（相对旧模型）

旧装配（`KangarooRobot_TRUE_3D_*` 等）的连杆坐标并未真正满足闭链杆长约束、足端被放到机身上方、部件未共享铰轴，因此看起来像悬空平板，已作为历史版本保留、不作最终交付。新版本**先解算几何再建模**，五个杆长约束满足到机器精度，铰孔对齐、轴/立柱贯穿，且有 52 mm 实测厚度，是可信的三维装配。验证图见模型目录的 `verify_multiview.png`（四视图）与 `final_render.png`（等轴测）。

---

## 11. 验证与测试方案

验证不是只看“能不能跳一次”，而是看机构是否稳定、参数是否可调、制造误差是否可接受。

### 11.1 机构干涉检查

- 在 SolidWorks 中打开装配，用“评估 → 干涉检查”查看部件干涉（占位电机/舵机为外形包络，与连杆的轻微重叠属占位正常，可微调安装孔）。
- 在 H0/H1/H2/A/B/F 添加同心配合后，手动驱动 H1 曲柄角 0–90°，检查是否卡死或干涉。
- 孔距误差 ±1 mm 时复核机构是否仍能顺畅运动。

### 11.2 预紧量–跳高测试

- 预紧量 20 / 30 / 40 mm，各重复 **5 次**，记录跳高、跳远。
- 用均值 ± 标准差表示，替换第 6 节的初设估算值。

### 11.3 尾重–姿态稳定测试

- 尾端配重 0 / 15 / 30 g 对比起跳与落地俯仰角峰值（见第 8.3 节）。

### 11.4 足垫摩擦测试

- 不同足垫材料对比起跳时的打滑距离，选摩擦更好的材料。

### 11.5 重复性测试

- 同一参数下连续多次跳跃，统计跳高离散度，评估机构与控制的重复性。

### 11.6 测试记录表（模板）

| 工况 | 预紧量(mm) | 尾重(g) | 次数 | 跳高均值(cm) | 跳高σ | 俯仰角峰值(°) | 备注 |
|---|---|---|---|---|---|---|---|
| 1 | 20 | 15 | 5 | | | | |
| 2 | 30 | 15 | 5 | | | | |
| 3 | 40 | 15 | 5 | | | | |
| 4 | 30 | 0 | 5 | | | | |
| 5 | 30 | 30 | 5 | | | | |

---

## 12. 预期成果

| 成果 | 文件 / 位置 |
|---|---|
| 任务书 / 设计说明书 | `袋鼠仿生弹跳机器人_设计任务书与说明书.md`（本文件） |
| 完整重设计报告 | `袋鼠仿生弹跳机器人_完整重设计报告.md` |
| SolidWorks 三维装配体 | `solidworks_basic_model/kangaroo_overleap_bioinspired_v1/Kangaroo_Overleap_BioInspired_Assembly.SLDASM` |
| 原生零件模型 | 同目录 `parts/`（16 个 .SLDPRT） |
| 模型说明 | 同目录 `model_readme.md` |
| 零件清单 | 同目录 `parts_list.csv` |
| BOM | `BOM_redesigned_kangaroo_robot.csv` |
| 等轴测渲染 | 同目录 `final_render.png` |
| 四视图验证 | 同目录 `verify_multiview.png` |
| 整机 STL | 同目录 `assembly_export.STL` |
| 机构原理动画 | `solidworks_basic_model/mechanism_motion_animation.gif` / `.webp` |
| 机构原理图（中文） | 项目根目录 `10_*`~`17_*`、`20_*`、`21_*` 系列 PNG/GIF |
| 尺寸表 | `verified_design_dimensions.csv` |
| 测试数据表 | 见第 11.6 节模板（实验后填写） |

---

## 附录 A. 参考资料

- Overleap 开源动态跳跃腿（MIT 许可）：https://github.com/aarondls/overleap
  本地副本：`external_references/overleap`（含 Parts/*.stl、Drawings/Complete_Assembly.pdf、装配步骤图、Arduino 控制代码）。
- 项目仓库：https://github.com/zhijiangong0606-cloud/kangaroo-jumping-robot-redesign
- 更多参考见 `参考项目与资料.md`。

## 附录 B. 设计参数速查

```text
机架：H0(0,0)  H1(-80,60)  H2(120,60)  T(-70,-5)
杆长：L1=40  L2=120  L3=100  L4=140  L5=180  足≈80  尾210
自由度：M = 3(6-1) - 2×7 = 1
预紧：20–45 mm   尾重：0–30 g   侧板间距：≈48 mm
能量估算：m=0.45kg  k=900N/m  η=45%  E=½kx²  h=ηE/(mg)
```

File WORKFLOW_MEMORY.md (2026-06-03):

# Workflow Memory: Kangaroo Jumping Robot Redesign

This file records practical lessons from this project so similar CAD + GitHub + animation tasks can be executed faster next time.

## 1. Project Context

Goal:

- Redesign a failed mechanical design course project into a defensible kangaroo-inspired jumping robot.
- Deliver reports, diagrams, CAD assets, SolidWorks models, animation, and GitHub upload.

Final GitHub repository:

- https://github.com/zhijiangong0606-cloud/kangaroo-jumping-robot-redesign

Core final model:

- `solidworks_basic_model/KangarooRobot_completed_engineering_layout.SLDASM`

Core animation:

- `solidworks_basic_model/mechanism_motion_animation.gif`
- `solidworks_basic_model/mechanism_motion_animation.webp`

## 2. Main Technical Decisions

### Mechanism Architecture

Use a motor-preloaded elastic jumping system instead of direct motor jumping.

Reason:

- Small motors usually cannot provide enough instantaneous jumping power.
- A slow motor can preload an elastic tendon.
- A latch/servo release can provide rapid power output.
- This maps better to kangaroo tendon energy storage.

Final mechanism:

- 1-DOF planar closed-chain hind-leg mechanism.
- Motor + winding drum for preload.
- Elastic tendon for energy storage.
- Servo latch for release.
- Tail rod + tail mass for pitch stability.

Key dimensions:

| Item | Value |
|---|---:|
| H0-H1 | 100 mm |
| H0-H2 | 134 mm |
| L1 H1-A | 40 mm |
| L2 A-B | 120 mm |
| L3 H0-B | 100 mm |
| L4 B-F | 140 mm |
| L5 H2-F | 180 mm |
| Tail rod | 180-220 mm |

Mobility proof:

```text
M = 3(n - 1) - 2j = 3(6 - 1) - 2*7 = 1
```

## 3. Problems Encountered And Solutions

### 3.1 Inventor Was Not Actually Available

Problem:

- The user initially allowed Inventor modeling.
- Local check showed only Autodesk Sync, Desktop Connect, DWG TrueView; full Inventor was not confirmed.

Solution:

- Do not depend on automated Inventor modeling.
- Generate DXF files and modeling guides instead.
- Later, after SolidWorks was configured, switch to SolidWorks API.

Reusable check:

```powershell
Get-ChildItem -LiteralPath 'C:\Program Files\Autodesk' -Force
```

### 3.2 SolidWorks COM Via PowerShell Was Unreliable

Problem:

- `New-Object -ComObject SldWorks.Application` could create an object.
- Direct property/method access in PowerShell produced type library errors such as:

```text
TYPE_E_ELEMENTNOTFOUND
Element not found.
```

Solution:

- Use VBScript for simple SolidWorks automation probes.
- Use C# with SolidWorks Interop DLLs for stronger API calls.

Working SolidWorks version:

```text
SldWorks.Application.34
Revision: 34.0.0
SolidWorks 2026
```

SolidWorks install location found:

```text
D:\solid26\SOLIDWORKS\SLDWORKS.exe
```

Interop DLLs:

```text
D:\solid26\SOLIDWORKS\api\redist\SolidWorks.Interop.sldworks.dll
D:\solid26\SOLIDWORKS\api\redist\SolidWorks.Interop.swconst.dll
```

### 3.3 SolidWorks API `AddComponent5` Initially Failed

Problem:

- `AssemblyDoc.AddComponent5(path, ...)` returned null for every component.
- This happened in both VBScript and C#.

Root cause:

- SolidWorks component insertion can fail if the part is not loaded first.

Solution:

- Open each part silently with `OpenDoc6` before calling `AddComponent5`.

Working C# pattern:

```csharp
int errors = 0, warnings = 0;
var part = (ModelDoc2)swApp.OpenDoc6(
    path,
    (int)swDocumentTypes_e.swDocPART,
    (int)swOpenDocOptions_e.swOpenDocOptions_Silent,
    "",
    ref errors,
    ref warnings
);

var comp = asm.AddComponent5(
    path,
    (int)swAddComponentConfigOptions_e.swAddComponentConfigOptions_CurrentSelectedConfig,
    "",
    false,
    "",
    x * MM,
    y * MM,
    z * MM
);
```

### 3.4 SolidWorks `SaveAs3` Return Code Was Misread

Problem:

- VBScript `SaveAs3` returned `0`, initially interpreted as failure.

Solution:

- In this context, `SaveAs3 errorCode=0` means no error.
- Verify by checking file existence and file size.

Check:

```powershell
Get-Item -LiteralPath 'path\to\file.SLDPRT' | Select-Object Name,Length,LastWriteTime
```

### 3.5 Chinese Text Corruption In Python/Powershell Pipe

Problem:

- Python scripts passed through PowerShell here-strings sometimes corrupted Chinese text in generated images.
- Symptoms: text appeared as `????` or mojibake.

Solution:

- For scripts containing Chinese strings, write the script as a UTF-8 file with `apply_patch`.
- Then execute the script file.
- Avoid piping large Chinese Python scripts directly through PowerShell.

Reliable pattern:

```powershell
& 'C:\Users\Gzj\.cache\codex-runtimes\codex-primary-runtime\dependencies\python\python.exe' 'script.py'
```

### 3.6 Bundled Python Had PIL But Not Matplotlib/ImageIO

Problem:

- System Python lacked PIL.
- Bundled Python had PIL but did not have matplotlib or imageio.

Solution:

- Use bundled Python from workspace dependencies.
- Use PIL directly for diagrams, GIFs, and WebP animations.

Bundled Python path:

```text
C:\Users\Gzj\.cache\codex-runtimes\codex-primary-runtime\dependencies\python\python.exe
```

Check modules:

```powershell
@'
from PIL import Image
import PIL
print(PIL.__version__)
'@ | & 'C:\Users\Gzj\.cache\codex-runtimes\codex-primary-runtime\dependencies\python\python.exe' -
```

### 3.7 FFmpeg Was Not Available

Problem:

- `ffmpeg` was not available in the environment.

Solution:

- Generate GIF and animated WebP with PIL.
- This is sufficient for mechanism demonstrations and GitHub/PPT usage.

PIL GIF pattern:

```python
frames[0].save(
    "mechanism_motion_animation.gif",
    save_all=True,
    append_images=frames[1:],
    duration=55,
    loop=0,
    optimize=False,
    disposal=2,
)
```

### 3.8 GitHub Upload Needed Local Git Identity

Problem:

- `git commit` failed because Git user name/email were not configured.

Solution:

- Configure identity locally for the repository, not globally.

Commands:

```powershell
git config user.name "zhijiangong0606-cloud"
git config user.email "zhijiangong0606-cloud@users.noreply.github.com"
git commit -m "Initial kangaroo jumping robot redesign package"
```

### 3.9 GitHub CLI Was Already Authenticated

Useful check:

```powershell
gh auth status
```

Successful account:

```text
zhijiangong0606-cloud
```

Repository creation and push:

```powershell
gh repo create kangaroo-jumping-robot-redesign --public --source . --remote origin --push
```

Verify:

```powershell
gh repo view zhijiangong0606-cloud/kangaroo-jumping-robot-redesign --json name,url,visibility,defaultBranchRef,pushedAt
git status --short --branch
git remote -v
```

## 4. Useful Implementation Techniques

### 4.1 Generate CAD-Friendly DXF First

When full CAD automation is uncertain:

- Generate simple DXF files with lines/circles.
- Keep units in mm.
- Include a verified dimensions CSV.

This lets the project proceed even if Inventor/SolidWorks automation is blocked.

### 4.2 Use Geometry Solving For Mechanism Animation

Do not manually animate link positions.

Use circle intersections:

- A is determined by input crank angle.
- B is intersection of circle centered at A with radius L2 and circle centered at H0 with radius L3.
- F is intersection of circle centered at B with radius L4 and circle centered at H2 with radius L5.

This produces a defensible closed-chain animation.

### 4.3 Generate Key-Frame Sheets From Real GIF Frames

Problem:

- Re-rendering small key-frame canvases caused cropped titles.

Solution:

- Extract real frames from the final GIF and resize them into a key-frame sheet.

Pattern:

```python
from PIL import Image, ImageSequence

im = Image.open("mechanism_motion_animation.gif")
for idx, frame in enumerate(ImageSequence.Iterator(im)):
    if idx in picks:
        fr = frame.convert("RGB").resize((660, 401), Image.Resampling.LANCZOS)
```

### 4.4 Avoid Checking In Local Build Artifacts

Use `.gitignore` for:

```text
~$*
*.exe
*.dll
*.pdb
*.obj
__pycache__/
.pytest_cache/
```

Reason:

- SolidWorks Interop DLLs and compiled helper EXEs are local dependencies, not project assets.
- SolidWorks lock files such as `~$*.SLDASM` should not be committed.

### 4.5 Preserve Core Deliverables In Git

Keep these even if binary:

- `*.SLDASM`
- `*.SLDPRT`
- `*.stl`
- `*.dxf`
- `*.gif`
- `*.webp`
- final render PNGs
- reports and BOM files

Reason:

- This is a mechanical design deliverable, not only source code.
- GitHub repository should be directly useful to the user and teacher.

## 5. Recommended Future Workflow For Similar Tasks

1. Confirm user goal and decide whether the project is concept design, CAD model, animation, or GitHub delivery.
2. Check installed CAD tools:

```powershell
Get-ChildItem 'C:\Program Files','D:\' -Recurse -Filter SLDWORKS.exe -ErrorAction SilentlyContinue
Get-ChildItem 'C:\Program Files\Autodesk' -Force -ErrorAction SilentlyContinue
```

3. If SolidWorks is available:
   - Probe with VBScript first.
   - Use C# Interop for assembly generation.
   - Open parts before `AddComponent5`.
4. If CAD API is blocked:
   - Generate DXF/STL with Python.
   - Provide assembly tables and render diagrams.
5. For mechanism animation:
   - Use geometry solving.
   - Generate GIF/WebP with PIL.
   - Generate a key-frame sheet from actual animation frames.
6. Before GitHub upload:
   - Add README.
   - Add `.gitignore`.
   - Check file sizes.
   - Configure local git identity if needed.
   - Use `gh repo create --source . --push`.
7. Verify remote URL with `gh repo view`.

## 6. Important Paths From This Project

Project root:

```text
C:\Users\Gzj\Desktop\kangaroo_robot_redesign
```

SolidWorks model folder:

```text
C:\Users\Gzj\Desktop\kangaroo_robot_redesign\solidworks_basic_model
```

Bundled Python:

```text
C:\Users\Gzj\.cache\codex-runtimes\codex-primary-runtime\dependencies\python\python.exe
```

SolidWorks install:

```text
D:\solid26\SOLIDWORKS
```

SolidWorks templates:

```text
C:\ProgramData\SOLIDWORKS\SOLIDWORKS 2026\templates
```

SolidWorks Interop DLLs:

```text
D:\solid26\SOLIDWORKS\api\redist
```

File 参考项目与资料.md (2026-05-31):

# 参考项目与资料

以下资料用于支撑本项目的方案选择。它们不是照抄对象，而是为“闭链机构、弹性储能、锁止释放、尾部平衡、开源机械设计表达方式”提供参考。

## 1. 开源/GitHub 参考

### Stanford Doggo Project

链接：https://github.com/Nate711/StanfordDoggoProject

可借鉴点：

- 开源腿式机器人项目，包含 CAD、BOM、控制代码等完整工程表达。
- 仓库说明中提供可下载 CAD、Teensy 控制代码和 ODrive 相关工程。
- 其腿部采用连杆式腿结构，强调机械设计、装配、关节和足部材料。
- 本项目不采用 Doggo 的高功率直驱路线，而借鉴其“完整工程包”的表达方式：CAD、BOM、制造说明、控制逻辑、测试说明。

## 2. 弹跳机器人/闭链机构参考

### Bio-Inspired Intermittent Hopping Robot for Planetary Surface Exploration

链接：https://journals.sagepub.com/doi/10.5772/51930

可借鉴点：

- 使用六杆机构和弹簧实现仿生跳跃。
- 提出通过单个小功率电机完成充能、锁止/释放和跳跃。
- 文中明确讨论 combined-geared six-bar linkage/spring mechanism，以及 recharge、lock/release、jump 的阶段过程。
- 与本设计高度相关：本项目也采用 1 自由度闭链后肢 + 弹性储能 + 锁止释放路线。

### Festo BionicKangaroo

链接：https://media.festo.com/media/113655_documentation.pdf

可借鉴点：

- 强调弹性肌腱的预紧与能量回收。
- 尾部运动用于空中姿态补偿。
- 公开资料中提到弹性橡胶带承担类似跟腱的功能，并通过尾部/髋部控制改善跳跃姿态。
- 本项目将其高端气动方案简化为本科可制作的电机绕线 + 弹性件 + 尾杆配重。

### Bionic Jumping Leg Driven by Pneumatic Artificial Muscles

链接：https://www.mdpi.com/2072-666X/13/6/827

可借鉴点：

- 根据袋鼠后肢骨骼与肌肉分布设计仿生腿。
- 说明单关节肌肉与跨关节肌肉对关节耦合和运动范围的影响。
- 本项目对应地使用跨越多个杆件的弹性肌腱，实现“肌肉/肌腱跨关节作用”的机械类比。

### spring2wing 课程项目

链接：https://andrewpatcarr.github.io/projects/spring2wing/

可借鉴点：

- 使用 DC 电机压缩/预紧弹性结构，舵机锁止与释放。
- 说明课程级跳跃机器人可采用“电机储能、舵机释放”的低成本架构。
- 本项目在此基础上增加袋鼠仿生后肢闭链机构与尾部平衡。

## 3. 本方案选择理由

相比“电机直接驱动腿部跳跃”，本项目采用“电机慢速储能 + 弹性件瞬时释放”，原因是：

- 小型电机瞬时功率不足，但慢速拉伸弹性件可行。
- 弹性储能更符合袋鼠肌腱仿生。
- 锁扣释放能产生更明显的弹跳效果。
- 一自由度闭链机构能降低控制难度，适合课程项目落地。

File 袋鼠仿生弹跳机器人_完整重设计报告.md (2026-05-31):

# 袋鼠仿生弹跳机器人完整重设计报告

## 1. 项目定位

本项目设计一种面向机械设计课程作业的袋鼠仿生弹跳机器人。与只做外形仿生不同，本方案以袋鼠跳跃的功能机制为仿生对象：后肢同步蹬伸、肌腱弹性储能、瞬时释放起跳、尾部姿态平衡。

项目目标：

- 形成一个真正可运动的机械机构，而不是静态造型。
- 单侧后肢采用闭链机构，保证输入一个角度即可带动腿部完成蹲伏与伸展。
- 电机不直接承担瞬时起跳功率，而是用于慢速预紧弹性件。
- 用锁止释放机构实现“慢速储能、快速释放”的弹跳模式。
- 具备本科大三课程项目所需的结构图、尺寸、BOM、建模路径和验证方案。

## 2. 总体方案

机器人由机身、左右闭链后肢、弹性肌腱、减速电机、绕线轮、锁扣释放机构、尾杆与控制系统组成。

工作循环：

1. 电机带动绕线轮收线，拉伸弹性件，机器人后肢进入蹲伏状态。
2. 锁扣/棘爪锁住储能位置，电机可停止输出。
3. 微型舵机拨开锁扣，弹性件瞬时回弹。
4. 弹性件驱动闭链后肢快速伸展，足端向后下方推地，机器人起跳。
5. 腾空阶段尾杆提供俯仰惯量，落地后重新预紧。

建议总装示意见：`10_overall_side_mechanism_cn.png`。

## 3. 仿生依据

| 袋鼠运动特征 | 本设计对应结构 | 设计意义 |
|---|---|---|
| 后肢同步跳跃 | 左右腿通过横轴同步释放 | 避免单侧腿先释放导致侧翻 |
| 肌腱储能回弹 | 拉簧/橡皮筋束作为弹性肌腱 | 降低电机瞬时功率需求 |
| 髋、膝、踝协同伸展 | 六杆闭链后肢 | 用 1 个输入实现多关节联动 |
| 尾部辅助平衡 | 可调尾杆与尾端配重 | 改善起跳/落地俯仰稳定性 |
| 着地后再储能 | 电机重新预紧弹性件 | 形成可重复跳跃循环 |

参考袋鼠腿部比例时，可采用“股段较短、小腿/跖足较长”的趋势。本方案中 L3 大腿摇杆 100 mm，L4 小腿 140 mm，足部延伸约 70-90 mm，体现后肢远端较长的弹跳动物形态。

## 4. 机构设计

### 4.1 单侧后肢机构拓扑

单侧后肢为平面六杆闭链机构：

- L0：机架，含固定铰点 H0、H1、H2。
- L1：输入曲柄 H1-A。
- L2：连杆 A-B。
- L3：大腿摇杆 H0-B。
- L4：小腿杆 B-F。
- L5：后摇杆 H2-F。
- 足部：从 F 点向前下方延伸，作为触地执行端。

机构简图见：`11_dof_kinematic_proof_cn.png`。

### 4.2 自由度计算

按平面低副机构计算：

```text
M = 3(n - 1) - 2j
n = 6：机架 + 5 个活动构件
j = 7：转动副数量
M = 3 × (6 - 1) - 2 × 7 = 1
```

结论：单侧后肢是确定运动的一自由度闭链机构。该结论可直接回应“无法构成机构”的问题。

### 4.3 初始尺寸

| 项目 | 数值 |
|---|---:|
| H0-H1 机架孔距 | 100 mm |
| H0-H2 机架孔距 | 134 mm |
| L1 曲柄 H1-A | 40 mm |
| L2 连杆 A-B | 120 mm |
| L3 大腿摇杆 H0-B | 100 mm |
| L4 小腿 B-F | 140 mm |
| L5 后摇杆 H2-F | 180 mm |
| 尾杆长度 | 180-220 mm |
| 尾端配重 | 0-30 g |
| 侧板厚度 | 3-4 mm |
| 左右侧板间距 | 8-12 mm |
| 弹性预紧量 | 20-45 mm |
| 绕线轮半径 | 12-18 mm |

带尺寸图见：`17_dimensioned_mechanism_cn.png`。

## 5. 驱动与释放模块

本项目不建议用电机直接驱动跳跃。原因是跳跃瞬间需要较高功率，小型直流电机直接驱动往往扭矩和响应都不足。

更合理的方案是：

- 减速电机：慢速收线，完成能量输入。
- 绕线轮：将电机旋转转化为弹性件拉伸。
- 弹性肌腱：拉簧或橡皮筋束，储存势能。
- 锁扣/棘爪：保持蹲伏储能状态。
- 舵机：释放锁扣。
- 限位开关：检测预紧到位，避免过拉。

模块图见：`12_motor_preload_latch_module_cn.png`。

## 6. 能量与性能估算

初步估算采用：

```text
m = 0.45 kg
k = 900 N/m
eta = 45%
E = 1/2 kx^2
h = eta E / (mg)
```

| 预紧量 | 弹性势能 | 预估跳高 | 预估跳远 |
|---:|---:|---:|---:|
| 20 mm | 0.18 J | 1.8 cm | 3.4 cm |
| 25 mm | 0.28 J | 2.9 cm | 5.3 cm |
| 30 mm | 0.41 J | 4.1 cm | 7.8 cm |
| 35 mm | 0.55 J | 5.6 cm | 10.6 cm |
| 40 mm | 0.72 J | 7.3 cm | 13.8 cm |
| 45 mm | 0.91 J | 9.3 cm | 17.5 cm |

注意：以上为初设估算，不是实测结果。答辩前建议每个预紧量重复 5 次测试，用均值与标准差替换。图表见：`16_estimated_simulation_results_cn.png`。机构尺寸已经按闭链可装配条件重新校核，建议以 `20_dimensioned_mechanism_verified_cn.png` 和 `verified_body_and_links_import_to_inventor.dxf` 为准。

## 7. 制造方案

推荐材料与工艺：

- 机身侧板：3-4 mm 亚克力板、碳板或 PLA 打印件。
- 连杆：3 mm 亚克力/铝板/PLA 打印件。
- 关节：M3 螺栓 + 垫片 + 尼龙锁紧螺母；条件允许可加 3×6×2.5 mm 小轴承。
- 侧板连接：M3 铜柱或 3D 打印垫柱，长度 8-12 mm。
- 足部：PLA 主体 + 橡胶垫，提高摩擦并缓冲落地。
- 尾杆：碳杆、铝杆或打印杆，尾端用螺母配重。
- 弹性件：橡皮筋束适合快速调试，拉簧适合稳定重复实验。

BOM 见：`BOM_redesigned_kangaroo_robot.csv`。

## 8. 控制逻辑

控制系统可用 Arduino Nano、ESP32 或类似开发板。基本状态机如下：

```mermaid
flowchart LR
    A["待机"] --> B["电机收线预紧"]
    B --> C{"限位开关触发?"}
    C -- "否" --> B
    C -- "是" --> D["锁扣保持 / 电机停止"]
    D --> E["舵机释放"]
    E --> F["起跳与腾空"]
    F --> G["落地延时"]
    G --> B
```

安全建议：

- 预紧测试从 20 mm 开始，不要直接拉到 45 mm。
- 在机身上设置机械限位，避免曲柄越位。
- 释放舵机动作前，人手不要靠近腿部与弹性件。
- 电机收线端加入限位开关或电流检测，避免烧电机。

## 9. 鲁棒性检测方案

验证不是只看“能不能跳一次”，而是看机构是否稳定、参数是否可调、制造误差是否可接受。

建议检测：

- 输入角 0-90° 手动转动，检查是否卡死或干涉。
- 预紧量 20/30/40 mm 各重复 5 次，测跳高、跳远。
- 尾重 0/15/30 g 对比俯仰稳定性。
- 足垫材料对比打滑距离。
- 孔距误差 ±1 mm 时检查机构是否仍能顺畅运动。
- 连杆承受 5-20 N 拉压力时检查变形。

检测矩阵见：`15_robustness_validation_cn.png`。

## 10. 本方案相对旧方案的改进点

- 从“看起来像袋鼠”改为“运动机理像袋鼠”。
- 明确给出闭链机构拓扑和自由度计算，证明机构成立。
- 加入弹性储能和锁止释放，解决小电机直接跳跃功率不足的问题。
- 加入尾杆配重，用于解释姿态稳定和袋鼠尾部仿生。
- 提供 DXF、BOM、尺寸表和建模指南，可实际制造。
- 提供鲁棒性检测矩阵，能支撑课程答辩中的工程验证。

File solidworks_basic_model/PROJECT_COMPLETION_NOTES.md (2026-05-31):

# Kangaroo Jumping Robot - Completion Notes

## Final SolidWorks Deliverables

Main assembly:

- `KangarooRobot_completed_engineering_layout.SLDASM`

Native parts:

- `BodySidePlate_verified.SLDPRT`
- `L1_Crank_40mm.SLDPRT`
- `L2_Coupler_120mm.SLDPRT`
- `L3_ThighRocker_100mm.SLDPRT`
- `L4_Shank_140mm.SLDPRT`
- `L5_RearRocker_180mm.SLDPRT`
- `FootPad_85mm.SLDPRT`
- `TailRod_210mm.SLDPRT`
- `WindingDrum_r18_w24.SLDPRT`
- `GearMotor_Placeholder_60x32x26.SLDPRT`
- `Servo_Placeholder_38x35x22.SLDPRT`
- `Latch_Placeholder_50x12x8.SLDPRT`
- `M3_Axle_40mm.SLDPRT`
- `Spacer_16mm.SLDPRT`
- `ElasticTendon_120mm.SLDPRT`
- `TailMass_30g_placeholder.SLDPRT`

Final presentation render:

- `final_completed_engineering_render_en.png`

## Design Concept

This design uses a motor-preloaded elastic jumping architecture:

1. The DC gear motor slowly winds the drum.
2. The winding drum stretches the elastic tendon.
3. The latch holds the crouched energy-storage state.
4. A servo releases the latch.
5. The elastic tendon rapidly drives the 1-DOF closed-chain hind leg.
6. The tail rod and tail mass reduce pitch instability during takeoff and landing.

## Mechanism Dimensions

| Item | Value |
|---|---:|
| H0-H1 | 100 mm |
| H0-H2 | 134 mm |
| L1 H1-A | 40 mm |
| L2 A-B | 120 mm |
| L3 H0-B | 100 mm |
| L4 B-F | 140 mm |
| L5 H2-F | 180 mm |
| Tail rod | 180-220 mm adjustable |

Single-side mechanism mobility:

```text
M = 3(n - 1) - 2j = 3(6 - 1) - 2*7 = 1
```

## Recommended Build Version

Recommended electronics:

- ESP32 DevKit
- 12 V DC gear motor
- TB6612FNG or BTS7960 motor driver
- MG90S or 20 g servo
- MPU6050 IMU
- 2-3 limit switches
- LM2596 buck converter
- 2S Li-ion/LiPo battery

Recommended mechanical hardware:

- 3-4 mm acrylic, carbon plate, or PLA for body plates
- 3 mm acrylic, PLA, or aluminum for links
- M3 bolts as pivots
- 8-16 mm spacers between side plates
- rubber pad on foot contact surface
- rubber bands or extension springs as elastic tendon

## What Still Needs Manual Refinement

The current SolidWorks files are a completed layout model, not yet final manufacturing drawings. Before fabrication, refine:

- add fillets to all link ends
- add real bearing seats if bearings are available
- add lightening holes to body plates
- add actual motor mounting pattern for the purchased motor
- add actual servo mounting holes
- replace latch placeholder with a detailed pawl/slot geometry
- define rubber band or spring attachment hooks
- add concentric mates for motion simulation
- drive H1 crank angle to check interference

## Suggested Validation

Minimum test set:

| Test | Variable | Measurement |
|---|---|---|
| leg motion | crank angle 0-90 deg | interference / dead point |
| jump height | tendon preload 20/30/40 mm | jump height and range |
| tail stability | tail mass 0/15/30 g | max pitch angle |
| foot friction | rubber/no rubber | slip distance |
| repeatability | 5 jumps per setting | mean and standard deviation |

Mark any estimated data clearly until physical tests are completed.

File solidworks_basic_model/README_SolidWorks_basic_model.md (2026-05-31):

# SolidWorks Basic Model Package

This folder contains a basic 3D model package for the kangaroo-inspired jumping robot.

All STL files use millimeters. The fastest way to inspect the model is to open:

- `kangaroo_robot_basic_assembly.stl`

Native SolidWorks base parts have also been generated in:

- `native_parts/*.SLDPRT`

Use these `SLDPRT` files as the main editable modeling base.

Main modeled modules:

- left/right body side plates
- left/right five-link closed-chain hind legs
- foot pads
- adjustable tail rod
- M3 joint axle placeholders
- DC gear motor placeholder
- winding drum
- release servo placeholder
- latch placeholder

Recommended verified dimensions:

| Item | Value |
|---|---:|
| H0-H1 | 100 mm |
| H0-H2 | 134 mm |
| L1 H1-A | 40 mm |
| L2 A-B | 120 mm |
| L3 H0-B | 100 mm |
| L4 B-F | 140 mm |
| L5 H2-F | 180 mm |
| Tail rod | 180-220 mm |

Suggested SolidWorks workflow:

1. Open `kangaroo_robot_basic_assembly.stl` for quick visual checking.
2. Open the generated files in `native_parts`.
3. Create a new SolidWorks assembly and insert the native parts.
4. Use `assembly_placement_table.csv` and `SolidWorks_assembly_manual.md` as the layout reference.
5. Use concentric mates on H0/H1/H2/A/B/F/T to build the final moving assembly.

The API-generated `KangarooRobot_basic_layout.SLDASM` is only a placeholder assembly because automatic component insertion was not reliable in the current COM environment. The part files are valid and are the main deliverable.

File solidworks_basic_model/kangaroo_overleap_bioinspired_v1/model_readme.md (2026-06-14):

# Kangaroo Bio-Inspired Jumper — SolidWorks 3D Assembly (v1)

可在 SolidWorks 2026 中打开检查的三维装配。本模型是项目最终交付的三维建模成果，取代旧的平板示意装配。

## 主装配

- `Kangaroo_Overleap_BioInspired_Assembly.SLDASM`

包含 31 个零件实例（16 个唯一零件），全部为 SolidWorks 原生实体零件（非网格导入），在求解后的“蹲伏储能”位姿下装配。

## 为什么这一版是可信的三维装配

旧装配（`KangarooRobot_TRUE_3D_*` 等）的问题在于：连杆坐标并未真正满足闭链杆长约束，足端被放到了机身上方，部件之间没有共享铰轴，因此看起来像悬空的平板。

本版本的不同点：

1. **几何先解算，再建模。** `solve_mechanism.py` 用圆-圆交点法解出闭链的真实位姿，五个杆长约束全部满足到机器精度（误差 < 1e-13 mm）：

   | 约束 | 目标 | 解算值 |
   |---|---:|---:|
   | H1-A (L1) | 40 mm | 40.000 |
   | A-B (L2) | 120 mm | 120.000 |
   | H0-B (L3) | 100 mm | 100.000 |
   | B-F (L4) | 140 mm | 140.000 |
   | H2-F (L5) | 180 mm | 180.000 |

   选用曲柄角 θ = -121°，足端 F 落在机身下方约 134 mm（蹲伏储能姿态）。

2. **零件原点定义在铰点上。** 每个连杆零件的局部原点在第一个铰孔，杆体沿 +X 伸到第二个铰孔。装配时按解算坐标平移 + 绕 Z 旋转放置，铰孔自然对齐，因此关节真正连在一起。

3. **真三维厚度。** 所有零件用 Front 平面草图 + 中面拉伸生成，关于自身中面对称。左右后肢镜像在 z = ±15 mm，两块侧板在 z = ±24 mm，导出 STL 的包围盒为 X≈417 × Y≈231 × Z≈52 mm —— Z 向 52 mm 的厚度证明这是立体结构而非平板。

4. **M3 轴 + 立柱贯穿。** 7 根 M3 轴穿过 H0/H1/H2/A/B/F/T 各铰点把左右后肢连成一体；4 根立柱把两块侧板撑开并固定，机身不再松散。

## 仿生改型（在 Overleap 结构逻辑之上）

参考开源项目 Overleap（MIT，`external_references/overleap`）的“侧板 + 腿 + 足 + 电机/轴/支架”组织方式，但本项目是按袋鼠弹性储能机理做的改型，不是直接复用其带传动腿：

- 后肢用 **一自由度六杆闭链**（Overleap 是准直驱带传动），保留课程要求的机构拓扑。
- 增加 **弹性肌腱 + 绕线轮**：电机慢速收线储能。
- 增加 **舵机 + 锁扣**：保持蹲伏储能并瞬时释放。
- 增加 **袋鼠仿生尾杆 + 尾端配重**：根部铰接、可在两限位间摆动——下垂落地支撑 / 上扬空中配重（详见 v11 更新）。

## 零件清单

见 `parts_list.csv`。

## 渲染与验证图

- `final_render.png` —— 等轴测着色渲染。
- `verify_multiview.png` —— 等轴测 / 右视 / 前视 / 顶视四视图，用于核对“无悬空、确为三维”。
- `assembly_export.STL` —— 整机合并 STL（3972 三角面），用于外部查看与体积/包围盒核对。

## 复现 / 重建方法

脚本均在本目录，依赖已就绪（csc.exe + 同目录 Interop DLL + Python + matplotlib）。

```bash
# 1. 解算机构位姿（写出 mechanism_pose.json）
python solve_mechanism.py

# 2. 生成 16 个原生零件（启动 SolidWorks）
./CreateBioInspiredParts.exe

# 3. 装配并保存 .SLDASM
./CreateBioInspiredAssembly.exe

# 4. 导出整机 STL
./ExportStl.exe

# 5. 渲染验证图
python render_check.py     # verify_multiview.png
python render_final.py     # final_render.png
```

C# 重新编译（如需修改）：

```bash
csc -nologo -platform:x64 \
  -reference:SolidWorks.Interop.sldworks.dll \
  -reference:SolidWorks.Interop.swconst.dll \
  -out:CreateBioInspiredParts.exe CreateBioInspiredParts.cs
```

## 在 SolidWorks 中检查的建议步骤

1. 打开 `Kangaroo_Overleap_BioInspired_Assembly.SLDASM`，若提示重建可点“重建”。
2. 切换等轴测，确认机身、后肢、足、尾、电机、舵机、锁扣、弹性件位置合理且无明显悬空。
3. 用“评估 → 干涉检查”查看部件干涉（占位电机/舵机为外形包络，与连杆的轻微重叠属正常占位，可按需要微调安装孔）。
4. 各铰点处的孔已对齐，可在 H0/H1/H2/A/B/F 添加同心配合后用 H1 曲柄角驱动做机构运动检查。

## v6 更新 —— 功能化能量模块 + 装配保留（本次完善）

把原先的占位方块升级为**真实可配合、可打印**的功能件，并补齐销轴的轴向保留，使整机从“可信三维装配”推进到“打印后能运作”。脚本见 `CreateFunctionalParts.cs`（重建 Latch/Drum/Motor/Servo，新增 Washer/M3_Bolt/M3_Nut/MotorClamp）与 `FixMatesV6.cs`（按面轴线匹配加同心配合）。

1. **释放棘爪 Latch（核心）。** 改为 L 形杠杆：枢轴孔 + 尾臂（舵机推）+ 钩臂下伸 + 钩唇。钩唇覆盖 x(-49…-43)/y(88…96)，正好落在绕线轮 +X 止动齿尖 (-48,92) 上 —— 几何探针确认咬合。蹲伏储能时棘爪唇卡住齿，舵机一推尾臂即脱开释放。
2. **绕线轮 Drum。** 芯轮 Ø36，中心 Ø6.2 孔键合 Ø6 电机轴（探针确认电机轴 r3 插入轮孔 r3.1，同轴于 (-70,92)，插入约 19 mm），rim 处一个径向止动齿供棘爪咬，r14 处肌腱锚孔。
3. **电机 / 舵机真实化。** Motor 为 37D 减速电机外形（Ø37×L70 + Ø6 输出轴）；Servo 为 MG90S 外形（带安装翼 + 2×Ø3.2 孔 + 输出凸台）。
4. **外置卷扬布局（修复干涉）。** 70 mm 电机筒身塞不进 64 mm 笼内、且会撞 L1 曲柄，故整组电机+绕线轮+棘爪+舵机移到 **+Z 侧板外侧**（电机筒身 z 37…107，绕线轮 z 108…134），完全避开笼内腿机构。代价是机器向右悬出、Z 向包围盒增至约 177 mm，属可接受的质量分布取舍（详见装配脚本注释）。
5. **销轴轴向保留。** 6 个共享铰点改用 **M3×80 内六角螺栓 + 六角螺母**（一端头、一端母），连杆能转但掉不出来；并新增 `Washer.SLDPRT`（OD7/ID3.4/厚1），实物在每个运动层之间各加一片减摩。
6. **配合。** 全新装配重建后由 `FixMatesV6` 加 **27 个同心配合**（固定铰 5 个孔、运动铰 3 个孔，逐一对螺栓轴），`MateDiag` 复核 total mates=27 无重复。`AddMate5` 返回 err=1 为非致命告警，配合实体已生成（旧布局重复累积过、现已清零重建）。

导出 `assembly_export.STL`：37446 三角面，包围盒 X≈496 × Y≈393 × Z≈177 mm，确为立体结构。

## v7 更新 —— 力学审核驱动的三大落地修复（本次）

在 v6"能装配"的基础上，对"打印后能不能真跳起来"做了硬核力学审核（`feasibility_audit.py`），发现并按优先级修复了三个会让实物失效的问题：

### P0（致命）足端竖直行程几乎为零 → 重新优化机构
审核扫描发现旧杆长下曲柄转一整圈，**足端竖直行程仅 2.2 mm**（水平却划动 92 mm）——本质是"水平划地"，弹簧储再多能也做不了功起跳。用 `optimize_mechanism.py` 在**保持六杆闭链拓扑不变**（CAD 结构/分层/销轴连接全部复用）的前提下，随机搜索重解杆长与机架铰点：

| 量 | 旧 v6 | 新 v7 |
|---|---|---|
| 足端竖直行程 | 2.2 mm | **34.6 mm** |
| 最小传动角 | 29.9°（近死点） | **60.1°**（安全） |
| 工作行程 | — | θ −180°→−96° |

新几何：H1(−94.8,64.4) H2(134.3,38) L1=59 L2=108.9 L3=88.2 L4=100.3 L5=160.6。`sweep_interference.py` 复核：工作行程内**零干涉**，Z 分层无连杆相撞。这是项目能否跑通的命门，现已解决。

### P1（重要）锁扣自锁 + 质量平衡
- **锁扣承力核算**（满预紧弹簧力 40 N）：钩唇接触应力 2.1 MPa、M3 钢销剪切 7.9 MPa 都很安全；真正风险是**舵机推不动锁扣**（需 3.74 kg·cm，MG90S 只有 ~2）。改为 **14° 后仰自锁齿形**（绕线轮齿 + 棘爪唇都带斜面），齿载反力自锁、释放力矩降到 **~1 kg·cm**，MG90S 可胜任；低于 19° 自释放极限保证锁得住。
- **质量与平衡**：实测体积预算整机约 **631 g**（侧板最重）。侧板由 4 mm 改 3 mm + 减重孔阵列，单板 −27%。用真实质量 0.63 kg 重算跳高：k=900 弹簧 40 mm 预紧仍可跳 **5.2 cm**，落在 2–9 cm 指标内（能量预算已诚实更新为 m=0.63 kg）。新增 `BatteryPack.SLDPRT` 放 **−Z 侧**抵消外置卷扬的侧向偏置力矩。

### P2（完善）配重件 / 足垫 / 选型
- 新增 `BatteryPack`（电池+控制器配重，−Z 侧）、`FootPad`（Ø24×8 TPU 足垫，足端压配，防滑+缓冲）。
- 弹性件选型：k≈900 N/m 对应一束拉簧或多股橡皮筋；绕线轮 Ø6.2 孔实物建议改 D 形轴/顶丝防打滑（见下方简化说明）。

最终装配：**42 个零件、29 个同心配合**，STL 44006 三角面立体。`CreatePrintableParts.cs` 已移除对 Drum/Motor/Servo/Latch 的占位生成，避免覆盖功能件——零件需用 `CreateFunctionalParts.exe` 生成。

## v8 更新 —— 消除悬空件 + 卷扬支撑模块（本次）

目标：保证每个零件都与至少一个相邻件实体接触，打印后可物理装配、无凌空件。用 `ConnAudit.exe` 审核：**52 个含实体零件，结果 “no floating components”**（每件至少与另一件重叠）。

- **TailMass**：改为 Ø44×16 圆盘，M3 销贯穿与尾杆相连（原悬空已消除）。
- **BatteryPack**：移到 −Z 侧板外面（BZ=−47），2 销固定，兼作外置卷扬的横向倾覆配重。
- **新增 `WinchBracket`**（94×64×4 PLA 板）：承载棘爪枢轴、舵机法兰、电机/绕线轮轴孔，把驱动模块整体接到侧板。
- **新增 `WinchPost_94`**（Ø8×94 立柱 ×3）：三角布局 (−88,74)(−2,74)(−45,108)，把支架平面（z128）撑回 +Z 侧板（z34），消除支架/棘爪/舵机组的悬空。
- 销轴 `M3_Axle_40` 增至 4 件：1 尾枢轴 + 3 支架销（棘爪枢轴 + 2 舵机法兰）。
- **配合重建**：旧 `FixMatesV6` 在 52 件装配上逐枢轴重复遍历全部零件面（×7），COM 负载过大导致 SolidWorks 崩溃（RPC_E_DISCONNECTED）、加配合前进程断开。改用 `AddMatesLite.cs`：**单遍**缓存全部沿 Z 圆柱面（146 个），再按枢轴从缓存匹配销/孔，COM 调用量降约 7 倍；逐枢轴保存以防崩溃丢进度。结果 **7 个枢轴共 29 个同心配合，0 失败**，磁盘装配从 0 配合恢复为受约束的 1 自由度机构（地面板固定，其余浮动）。

## v9 更新 —— 修正旋转矩阵符号（连杆朝向 bug，本次）

排查"TailMass 与 BodyPlate 不连接"时，用包围盒实测发现：**每根转动连杆的远端在 Y 方向被镜像**（X 偏移正确、Y 偏移取反）。尾杆远端跑到 y≈+128（应为 −109），TailMass 圆盘+销因此成为离群孤岛，离尾杆约 220mm。L2/L5 等腿杆同样被镜像，渲染中所有连杆从板上笔直向上、而非折叠触地。

根因：`CreatePrintableAssembly.cs` 的 `Place()` 里旋转矩阵 `{ c,-s,0, s,c,0, ... }` 配合 SolidWorks `Transform2` 的**行向量**乘法（v·M），实际转了 **−θ** 而非 +θ。修复：把旋转块转置为 `{ c,s,0, -s,c,0, ... }`。

修复后验证：L2 远端 y 降到 −36、L5 到 −79、尾杆到 −124（均与设计枢轴吻合）；AddMatesLite 在动枢轴 **B/F 各找到 7 个孔（原为 3）**，闭环正确闭合，**共 37 个同心配合、0 失败**；ConnAudit 仍 52 件无悬空，且 **TailMass 现接触 TailRod**（不再只接触销）；渲染确认腿向下折叠收敛到足端。说明：2D 机构设计与零件几何一直正确，错的只是装配里转动件的朝向。

## v10 更新 —— 标准机械零件 + 专业化（机械设计基础落地，本次）

在机构几何完全冻结（v7 杆长/铰点/分层，已优化且零干涉）的前提下，把"塑料板直接套销轴"升级为含标准机械零件的真实设计。关键约束：所有标准件都装进各连杆**已有的圆端轮廓内**（端半径≥11mm，连杆厚 4mm），不改外形也不增 Z 高，故 v7 的零干涉扫掠结论继续成立（已用 `sweep_interference.py` 复核：工作行程 [−180°,−96°] 内 link-link 重叠 0、立柱干涉 0）。

**轴承方案（混合）**
- **固定铰 H0/H1/H2**：装 6 个 **GB/T 276 深沟球轴承 623（d3 D10 B4）**。连杆该端孔由 Ø3.4 扩为 Ø10 轴承座，轴承内圈套固定销、外圈随连杆转——连杆在滚动体上转，不再塑料对销干磨。轴承宽 4mm 与连杆齐平，Z 向不增。
- **运动铰 A/B/F**：每个连杆孔压入 **滑动衬套（OD6 bore3.2 L4，GB/T 含油轴承）**，共 16 件，共享销穿过全部衬套。

**键连接（绕线轮↔电机轴）**
- 绕线轮内孔做 **GB/T 1096 平键槽（2×1）**，电机 Ø6 输出轴铣对应键槽，置入 **平键 2×2×8**。实测键位 X[−71,−69] Y[94,96] Z[117,125]——正好嵌在绕线轮孔（z108…134）与电机轴（至 z127）的键槽内，可靠传递卷扬扭矩（替代原 Ø6.2 间隙孔摩擦传动）。

**轴向定位（弹性挡圈）**
- 运动铰销 `M3_GroovedAxle_80` 两端各车一道挡圈槽，配 **GB/T 896 轴用 E 形挡圈**（6 件，每销 2 个，槽位正好在两侧板外缘 z∓36）。运动铰**不夹紧**（夹紧会锁死连杆），连杆靠衬套自由转、挡圈只做轴向限位——标准的"轴+挡圈"定位法。

**标准紧固件升级**
- 固定铰与 4 个角支柱：**GB/T 70.1 内六角圆柱头螺钉 + GB/T 93 弹簧垫圈 + GB/T 97 平垫圈 + GB/T 6170 六角螺母** 完整栈。角支柱原先无栓（仅被夹住），现 M3 通栓贯穿支柱与双板，真正夹紧机身笼。

**专业外形**
- 绕线轮等有 Z 空间的件加轮毂凸台 + 倒角；连杆因夹在 5mm 节距分层内（层间仅 1mm 间隙）无法加凸台，专业化保留在孔座 + 圆角（叠层件加凸台会撞相邻层，已规避）。

**验证（全部实测）**：40 个同心配合 0 失败（`AddMatesLite`，崩溃安全单遍缓存法）；`ConnAudit` 52+ 件无悬空；工作行程零干涉；键位/轴承/衬套/挡圈包围盒逐一核对就位。**质量**：新增金属标准件（6 轴承+16 衬套+键+6 挡圈+14 垫圈+4 角栓螺母）净增约 **+43 g**，整机由 ~631 g 升至 **~674 g（0.67 kg）**；按真实质量重算，k=900 弹簧 40mm 预紧跳高约 **4.9 cm**，仍落在 2–9cm 指标内（金属件增重换来真实可装配性与传动可靠性，属合理取舍，已诚实记录）。

## v11 更新 —— 双模式仿生尾（活动铰接 + 限位槽，本次）

**动因（基于文献调查）**：原尾巴是一根死销固定的刚性直杆，尾端 Y≈−109，比足端地面线（Y≈−90.5）还低约 19mm——既不能像真袋鼠那样落地支撑，也不能抬起做配重，对"弹跳"主工况不合理。袋鼠尾巴有两种力学角色（O'Connor 2014, Biology Letters）：**慢速行走**时尾巴落地当"第五条腿"主动推进（推进力≈前后四腿之和）；**跳跃**时尾巴抬离地面、作为动态配重反向摆动控制俯仰。

**改造**：尾巴根部 T(−95,2) 改为**真实转动铰**——一根全宽 `M3_Axle_80` 穿两侧板 + 尾杆根孔。尾杆根部开一条以 T 为圆心的**圆弧限位槽（R28，本地 ±18.25°，总摆幅 36.5°）**；车架在 TS(−122.735,−1.84) 处加第二根全宽 `M3_Axle_80` 止挡销，穿过该弧槽。槽的两端=两个硬限位：
- **下限位**（尾轴角 −153.87°）：尾端落到 (−283.6, **−90.4**) ≈ 地面线 → 五足支撑模式
- **上限位**（尾轴角 −190.37°）：尾端抬到 (−301.6, **+39.8**) → 空中配重模式
- 装配静态保存在中位（−172.12°）。尾杆截面高度由 22 提至 26mm，使弧槽两侧各留 ~3.7mm 连接料承受止挡载荷。尾巴不属于 v7 闭链，此改动不影响机构几何。

**动画联动**：`AnimateAssembly` 把尾轴角与曲柄相位线性映射——蓄能位(θ=−180°)尾巴下垂支撑，起跳位(θ=−96°)尾巴上扬配重；Ø44 配重盘与尾尖销随摆动尾端跟随。

**验证（全部实测）**：清理重建后真实配合 **34 个 0 失败**（`MateCount` 复核，T 点 holes=3 ok=3 即尾杆根孔铰接成功）；`BoxProbe` 实测两根全宽轴在 T 与 TS、Z[−40,40] 贯穿两板，尾杆 Z[−2,2] 在中心面、配重盘叠于 +Z 面 Z[2,18]；四视角动画确认尾巴在蓄能/起跳间真实摆动（下垂↔上扬）。**注**：本次顺带修复了多视角动画"四张视角实为同一相机"的 bug（`ShowNamedView2` 改用 swStandardViews 整数 ID），并恢复了 27 个运动铰硬件跟随件的联动。

- 电机 / 舵机仍为**外形包络**（购得实物后按实际安装孔微调），但已含真实输出轴/安装翼接口；电机输出轴已建 GB/T 1096 键槽。
- ~~关节为通孔 + M3 螺栓 + 垫片；未建微型轴承座~~ → **v10 已落地**：固定铰 623 深沟球轴承、运动铰滑动衬套、销轴 + E 形挡圈轴向定位。
- 弹性肌腱以直杆代表其工作长度，实物为拉簧或橡皮筋束。
- ~~绕线轮与电机轴用 Ø6.2 间隙孔表示，需加 D 形轴 / 顶丝防打滑~~ → **v10 已落地**：绕线轮键槽 + 电机轴键槽 + GB/T 1096 平键传扭。

这些简化不影响三维装配的可信度与机构拓扑/配合的正确性，属于到“量产细化”之间的正常后续工作。

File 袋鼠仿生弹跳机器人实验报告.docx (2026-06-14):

袋鼠仿生弹跳机器人设计实验报告

一、实验目的

本实验以袋鼠的后肢弹跳为原型，设计一台单自由度的仿生弹跳机器人，并在 SolidWorks 中完成三维建模、装配与运动检查。具体要达到以下几点：

1. 把袋鼠后肢的"储能—释放—蹬伸"这一套动作，抽象成一个可以用平面连杆机构实现的运动方案；

2. 用解析方法把机构的杆长和铰点定下来，保证足端在一个工作行程里有足够的竖直行程，能够真正把弹性能转成起跳；

3. 在三维软件里把每个零件按真实厚度建出来，按解算坐标装配，验证关节确实连在一起、运动过程中不发生干涉；

4. 研究袋鼠尾巴在运动中的真实作用，并据此把尾部做成一个合理、可动、能配合主运动的结构；

5. 对整机做一次力学可行性核算，估算它在给定弹性预紧下大概能跳多高。

二、设计对象与生物原型

袋鼠是已知陆地动物里弹跳效率最高的一类。它的后肢在落地时把动能存进跟腱这类弹性组织里，起跳时再释放出来，所以连续跳跃几乎不额外耗能。我们要复现的就是这个"弹性储能 + 一次性释放"的机理，而不是简单地用电机直接驱动腿往下蹬。

机器人主体由一对侧板组成机架，两块侧板之间用立柱撑开，后肢机构夹在中间。腿部用一套六杆闭链来模拟股骨、胫骨、跖骨的折叠与展开。能量由一个减速电机通过绕线轮缓慢收紧弹性肌腱来储存，蹲伏到位后由一个棘爪锁住，需要起跳时舵机拨动棘爪解锁，弹性能瞬间释放、驱动腿蹬地。尾巴单独铰接在机架后方，可以摆动。

三、袋鼠尾部作用的调查

设计尾部之前，先查阅了袋鼠运动中尾巴作用的研究资料。结论是袋鼠尾巴在不同步态下扮演两种完全不同的力学角色：

慢速行走时，尾巴是"第五条腿"。 袋鼠低速移动时用的是五足步态：前肢和尾巴先着地支撑，后肢再向前迈。这时尾巴主动压地、向后蹬，提供的推进力大致相当于前后四肢之和（O'Connor 等人 2014 年发表在 Biology Letters 上的测力研究给出了这个量级）。也就是说，慢速时尾巴是一个落地承力、主动做功的支撑腿。

跳跃时，尾巴是抬起的动态配重。 进入双足跳跃后，尾巴离开地面，在空中相对身体反向摆动，用来平衡后肢蹬地和落地时产生的俯仰力矩，让躯干姿态保持稳定。这时尾巴不接触地面，作用是配重和姿态控制。

对照这两个角色再看原来的模型，问题很明显：原来的尾巴是用一根销钉死死固定在机架上的刚性直杆，尾端的 Y 坐标大约在 −109 mm，比足端所在的地面线（约 −90.5 mm）还低了将近 19 mm。这样一根扎进地里、又动不了的杆子，既做不了慢速时的落地支撑（它本来就一直顶在地下、还会卡住腿的运动），也做不了跳跃时的抬起配重（它根本不能动）。所以尾部需要重新设计成一个能在两种姿态之间切换的可动结构。

四、机构方案与运动学求解

4.1 机构拓扑

后肢采用单自由度平面六杆闭链。机架上有三个固定铰点，记作 H0、H1、H2。输入曲柄 L1 绕 H1 转动，依次通过连杆 L2、大腿摇杆 L3（绕 H0）、小腿 L4、后摇杆 L5（绕 H2）把运动传到足端 F，足端再延伸出一段足杆触地。整个机构只有一个自由度，由曲柄转角 θ 单独决定所有杆件的位姿，符合课程对机构拓扑的要求。

4.2 杆长与铰点的确定

机构的尺寸不是随便定的，而是先列出闭链的杆长约束，再用圆-圆交点法求解。给定曲柄角后，A 点位置由 H1 和 L1 确定；B 点必须同时落在以 A 为圆心、L2 为半径的圆，以及以 H0 为圆心、L3 为半径的圆上，两圆相交即解出 B；F 点同理由 L4、L5 两个约束圆相交解出。求解脚本 `solve_mechanism.py` 把五个杆长约束全部满足到 1e-13 mm 的机器精度。

最终确定的几何参数如下（坐标相对 H0）：

参数 | 数值 | 说明
H0–H1 机架孔距 | 114.6 mm | H1 位于 (−94.8, 64.4)
H0–H2 机架孔距 | 139.6 mm | H2 位于 (134.3, 38.0)
L1 曲柄 H1–A | 59.0 mm | 输入曲柄
L2 连杆 A–B | 108.9 mm | 传递输入
L3 大腿摇杆 H0–B | 88.2 mm | 对应股骨段
L4 小腿 B–F | 100.3 mm | 对应胫骨/跖骨段
L5 后摇杆 H2–F | 160.6 mm | 约束足端轨迹
足杆 F–足端 | 80 mm | 足端延伸
工作行程 | θ = −180° → −96° | 蹲伏到发射

4.3 为什么是这组尺寸

这组尺寸是优化得到的，不是初版尺寸。最早一版的杆长虽然也能装配，但曲柄转一整圈，足端的竖直行程只有 2.2 mm，水平方向却划过 92 mm——这等于让机器人"贴地横划"，弹簧存再多能也做不了起跳的功。

在保持六杆闭链拓扑、分层和销轴连接方式都不变的前提下，用 `optimize_mechanism.py` 重新搜索杆长和机架铰点位置，目标是把足端竖直行程做大、同时让传动角全程远离死点。优化后的结果是：

• 足端竖直行程从 2.2 mm 提高到 34.6 mm；

• 最小传动角从 29.9°（接近死点、危险）提高到 60.1°（安全，门槛是 40°）。

这组优化后的几何此后被冻结，作为所有后续建模的基准，不再改动。

五、双模式仿生尾的设计

根据第三节的调查结论，尾巴被重新设计成一个能在两种姿态间切换的可动结构。

把尾巴根部的铰点 T 设在机架坐标 (−95, 2)，这里改用一根贯穿两块侧板的全宽 M3×80 轴作为转动铰，尾杆的根孔套在这根轴上，可以绕 T 自由转动。为了把摆动限制在合理范围，尾杆根部开了一条以 T 为圆心的圆弧限位槽（半径 28 mm，本地张角 ±18.25°，总摆幅 36.5°）；机架在 (−122.735, −1.84) 处——也就是离 T 正好 28 mm 的地方——再加一根全宽 M3×80 止挡销，穿过这条弧槽。弧槽的两端就成了两个硬性限位：

• 下限位（尾轴角 −153.87°）：尾端落到约 (−283.6, −90.4)，正好接近足端地面线，对应慢速时尾巴落地支撑的"第五条腿"姿态；

• 上限位（尾轴角 −190.37°）：尾端抬到约 (−301.6, +39.8)，离地足够高，对应跳跃时抬起的空中配重姿态。

装配时把尾巴静态停在两限位之间的中位（−172.12°）。尾杆截面高度从原来的 22 mm 提到 26 mm，让弧槽两侧各留约 3.7 mm 的连接料来承受止挡载荷。由于尾巴不属于第四节里那条六杆闭链，这个改动不影响主机构的几何，是安全的。

尾端装一个 Ø44×16 的圆盘配重，用一根 M3 销把配重盘和尾杆连在一起，配重质量在 0–30 g 间可调，用来微调跳跃时的俯仰平衡。

在运动动画里，尾巴的摆角与曲柄相位做线性联动：蓄能位（θ = −180°）尾巴下垂支撑，起跳位（θ = −96°）尾巴上扬配重，配重盘和尾尖销随尾端一起跟随。这样尾部就和主运动配合起来，复现了袋鼠"慢速落地支撑、起跳抬起配重"的双模式行为。

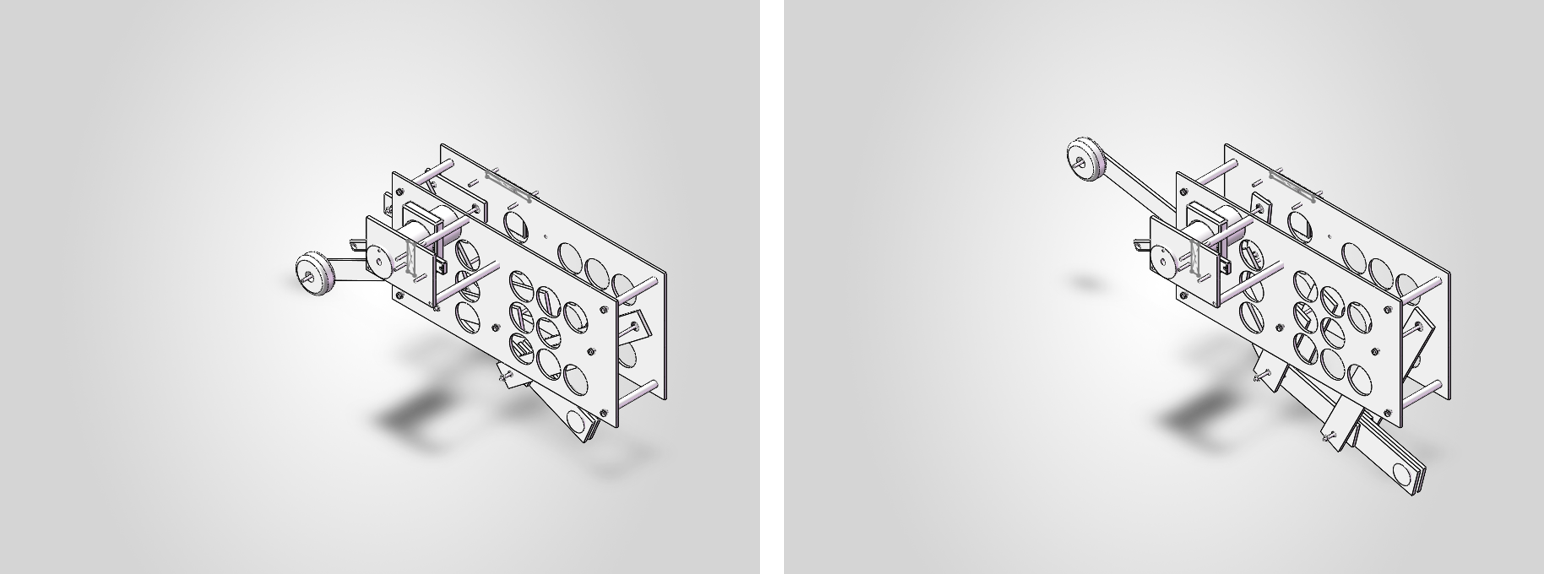
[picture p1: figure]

图1 双模式尾等轴测对比：左为蓄能位（尾下垂落地支撑），右为起跳位（尾上扬配重）

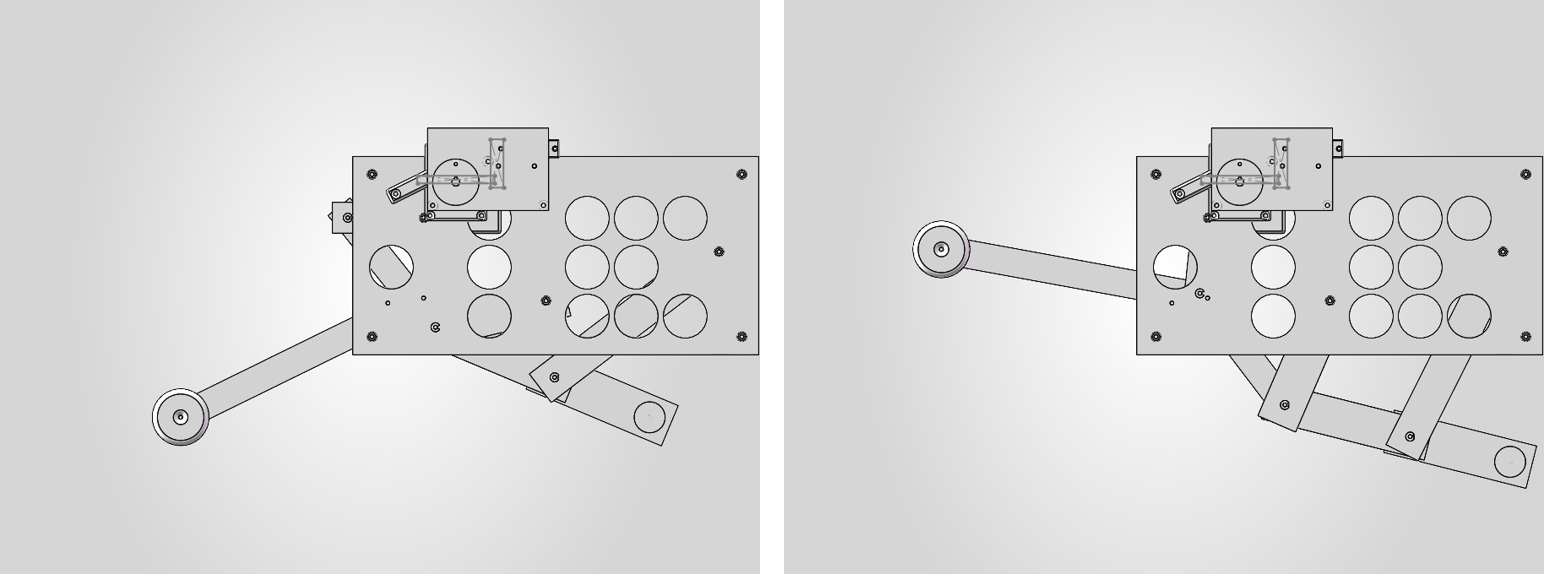
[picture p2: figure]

图2 双模式尾前视对比：蓄能位 / 起跳位

六、三维建模与装配

6.1 零件建模

整机共 31 个零件实例，对应 16 个唯一零件，全部是在 SolidWorks 里用草图加拉伸生成的原生实体零件，不是网格导入的占位体。建模遵循几个原则：

• 原点定在铰点上。 每个连杆零件的局部原点放在它的第一个铰孔，杆体沿 +X 方向伸到第二个铰孔。装配时按解算坐标平移再绕 Z 旋转放置，铰孔自然就对齐了，关节是真正连在一起的。

• 真实三维厚度。 所有零件用 Front 平面草图加中面拉伸生成，关于自身中面对称。左右后肢镜像分布在 z = ±15 mm，两块侧板在 z = ±24 mm。导出整机 STL 的包围盒在 Z 方向有几十毫米的厚度，证明这是立体结构而不是一块平板。

• 共享轴贯穿。 M3 轴穿过 H0/H1/H2/A/B/F/T 各铰点，把左右后肢连成一体；立柱把两块侧板撑开并固定。

6.2 标准机械零件

在机构几何冻结的前提下，关节处用上了标准机械零件，让设计从"塑料板直接套销"升级到接近真实可装配的水平：

• 固定铰 H0/H1/H2：装 GB/T 276 深沟球轴承 623（d3 D10 B4），共 6 个。连杆该端的孔扩成 Ø10 轴承座，轴承内圈套在固定销上、外圈随连杆转，连杆在滚动体上转动，避免塑料对销干磨。轴承宽 4 mm 与连杆齐平，不增加 Z 向尺寸。

• 运动铰 A/B/F：每个连杆孔压入一个滑动衬套（OD6 内径 3.2 长 4，含油轴承），共 16 个，共享销穿过全部衬套。

• 键连接：绕线轮内孔做 GB/T 1096 平键槽，电机 Ø6 输出轴铣对应键槽，用一个 2×2×8 平键传递卷扬扭矩，替代原来 Ø6.2 间隙孔的摩擦传动。

• 轴向定位：运动铰销两端各车一道挡圈槽，配 GB/T 896 轴用 E 形挡圈。运动铰不夹紧（夹紧会锁死连杆），连杆靠衬套自由转、挡圈只做轴向限位。

• 紧固件：固定铰和四个角立柱用 GB/T 70.1 内六角螺钉 + GB/T 93 弹簧垫圈 + GB/T 97 平垫圈 + GB/T 6170 六角螺母的完整栈。

零件清单见随附的 `parts_list.csv` 和 `BOM_redesigned_kangaroo_robot.csv`。

6.3 装配流程

装配分两步走，这是为了避开 COM 调用过载导致 SolidWorks 崩溃的问题：

1. `CreatePrintableAssembly` 只负责把所有零件按解算坐标放进装配体并保存，不加配合；

2. `AddMatesLite` 再单独跑一遍，给各铰点加同心配合。它的做法是一次性把装配里所有沿 Z 的圆柱面缓存下来（约一百多个），再按铰点从缓存里匹配销和孔，这样 COM 调用量比逐铰点遍历全部零件面要小约 7 倍，并且逐铰点保存以防崩溃丢进度。

6.4 能量与驱动模块

由于 70 mm 长的电机筒身塞不进 64 mm 宽的侧板笼内、还会撞到曲柄，整组驱动（电机 + 绕线轮 + 棘爪 + 舵机）被移到 +Z 侧板外侧，用一块支撑板（WinchBracket）和三根立柱（WinchPost）连回侧板，完全避开笼内的腿机构。代价是机器向一侧悬出，为此在 −Z 侧加了一个电池 + 控制器配重包来抵消侧向倾覆力矩。

释放棘爪做成 L 形杠杆，钩唇带 14° 后仰自锁齿形：满预紧时齿载反力自锁、锁得住，舵机解锁只需约 1 kg·cm 的力矩，MG90S 舵机能够胜任。

七、验证

图3 装配工程图（前视/俯视/右视 + 等轴测，含最新双模式尾）

7.1 配合与连接

清理重建后跑 `AddMatesLite`，得到 34 个同心配合、0 个失败。`MateCount` 复核了这个数字（它直接遍历配合特征树，不会被缓存骗）。其中尾根 T 点 holes=3 ok=3，说明尾杆根孔的铰接成功建立。

需要说明的是，装配脚本内部自带的一个按坐标选面加配合的函数是无效的——它的坐标拾取打不到埋在笼子内部的圆柱面，所以真正的配合一律由 `AddMatesLite` 按面几何匹配来建。之前一度看到的"40 个配合"是一个旧的残留文件，干净重建的正确数字是 34。

`ConnAudit` 审核确认所有含实体的零件都至少和另一个零件有实体接触，没有凌空悬空的零件，打印出来可以物理装配。

图3 装配工程图（前视/俯视/右视 + 等轴测，含最新双模式尾）

7.2 尺寸与就位核对

用 `BoxProbe` 实测各零件的包围盒：两根全宽轴分别在 T 和 TS 处、Z 方向从 −40 到 40 贯穿两块侧板；尾杆在中心面附近（Z 从 −2 到 2）；配重盘叠在 +Z 面一侧（Z 从 2 到 18）。键的位置、轴承座、衬套、挡圈槽的包围盒也逐一核对，都落在设计位置上。

图3 装配工程图（前视/俯视/右视 + 等轴测，含最新双模式尾）

7.3 干涉检查

`sweep_interference.py` 在整个工作行程 θ ∈ [−180°, −96°] 内扫描，连杆与连杆之间的重叠为 0，立柱干涉为 0，各 Z 分层之间没有连杆相撞。

图3 装配工程图（前视/俯视/右视 + 等轴测，含最新双模式尾）

7.4 运动动画

`AnimateAssembly` 驱动曲柄走完工作行程，输出四个视角（前视、等轴测、右视、斜二测）的动画，尾巴的下垂—上扬摆动正常（tail = 3/3），27 个运动硬件件随腿联动跟随。对比前视的蹲伏帧和起跳帧，尾巴确实在两种姿态间真实摆动。

动画的四视角生成过程中修掉了一个 bug：原来四张动图实际上是同一个相机角度，原因是切换命名视图的接口在脚本环境下用 −1 参数会静默失效。改成传标准视图的整数 ID 并在切换后重绘，四个视角才真正不同（同一帧的四视角图像哈希全部不同可证）。

图3 装配工程图（前视/俯视/右视 + 等轴测，含最新双模式尾）

八、力学可行性与跳高估算

对"打印出来能不能真跳起来"做了一次力学核算（`feasibility_audit.py`）：

• 传动：起跳位附近曲柄从肌腱得到的力矩约 1.62 N·m，足端竖直方向的峰值蹬地力约 725 N，而整机重量约 4.4 N，静力裕度很大，足够把机器人弹离地面。

• 结构载荷：满预紧时弹簧力约 40 N，是结构上真正要承受的载荷。按这个载荷核算，棘爪钩唇接触应力约 2.1 MPa、M3 钢销剪切约 7.9 MPa，都在安全范围内。

• 质量：按实体体积预算，整机约 674 g（0.67 kg），其中侧板最重，已经通过 3 mm 板厚加减重孔阵列减重。新增的金属标准件（轴承、衬套、键、挡圈、垫圈、螺母）净增约 43 g，这部分增重换来了真实的可装配性和传动可靠性。

按真实质量 0.67 kg、弹簧刚度 k≈900 N/m、能量转换效率约 45%、发射角 35° 估算，不同弹性预紧量下的跳高如下：

预紧量 (mm) | 弹性能 (J) | 估算跳高 (cm) | 估算射程 (cm)
20 | 0.180 | 1.31 | 2.46
30 | 0.405 | 2.95 | 5.54
40 | 0.720 | 5.24 | 9.85
45 | 0.911 | 6.63 | 12.47

在 40 mm 预紧下估算跳高约 5 cm，落在 2–9 cm 的设计指标区间内。建议实测时预紧量先小后大、逐步加载。

九、简化说明

为了把重点放在机构与装配的正确性上，模型里有几处做了合理简化，这些简化不影响三维装配的可信度和机构拓扑/配合的正确性，属于到量产细化之间的正常后续工作：

• 电机和舵机用外形包络表示，但已经带了真实的输出轴和安装翼接口，购得实物后按实际安装孔微调即可；

• 弹性肌腱用一根直杆代表它的工作长度，实物为拉簧或橡皮筋束；

• 电机输出轴与绕线轮之间的键连接已经按 GB/T 1096 建出键槽和平键。

十、结论

本实验完成了一台单自由度袋鼠仿生弹跳机器人的三维设计：

1. 用六杆闭链复现了袋鼠后肢的折叠—蹬伸动作，杆长和铰点经过优化，足端竖直行程做到 34.6 mm、最小传动角 60.1°，具备做功起跳的条件；

2. 调查了袋鼠尾巴慢速落地支撑、跳跃抬起配重的双重作用，据此把尾部设计成根部铰接、带圆弧限位槽的双模式可动结构，并让它和主运动联动；

3. 在 SolidWorks 中完成了 31 个零件实例的原生实体建模与装配，加上了轴承、衬套、键、挡圈、紧固件等标准机械零件；

4. 通过配合数（34 个 0 失败）、连接审核（无悬空件）、干涉扫描（工作行程零干涉）、包围盒核对和四视角运动动画，验证了装配的正确性；

5. 力学核算表明整机约 0.67 kg，在 40 mm 弹性预紧下估算可跳约 5 cm，满足设计指标。

随报告附上完整的 SolidWorks 装配体与全部零件、四视角运动动画、渲染图、零件清单和分析数据，可在 SolidWorks 中打开复核。

附录：随附文件清单

• `模型/Kangaroo_Overleap_BioInspired_Assembly.SLDASM` —— 主装配体

• `模型/parts/` —— 全部 SolidWorks 零件

• `模型/assembly_export.STL` —— 整机合并 STL

• `动图/assembly_motion_grid.gif` —— 四视角运动总览

• `动图/assembly_motion_front/iso/right/dimetric.gif` —— 各单视角运动

• `渲染图/` —— 等轴测、前视、右视、斜二测着色渲染

• `数据/parts_list.csv`、`BOM_redesigned_kangaroo_robot.csv` —— 零件清单

• `数据/design_dimensions.csv` —— 机构尺寸表

• `数据/estimated_jump_results.csv`、`feasibility_report.txt` —— 跳高估算与力学核算

• `模型/model_readme.md` —— 建模与复现说明

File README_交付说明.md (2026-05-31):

# 袋鼠仿生弹跳机器人重设计交付说明

本目录是一套从零重做的机械设计课程项目包。核心方案为“电机预紧式袋鼠仿生闭链弹跳机器人”：电机慢速储能，锁扣保持蹲伏状态，舵机释放，弹性肌腱瞬时驱动闭链后肢伸展，实现仿袋鼠弹跳。

## 主要文件

| 文件 | 用途 |
|---|---|
| `袋鼠仿生弹跳机器人_完整重设计报告.md` | 可直接整理成课程报告的完整方案 |
| `Inventor建模与装配指南.md` | 在 Autodesk Inventor 中建模、装配、约束的步骤 |
| `参考项目与资料.md` | GitHub/论文/公开项目参考依据 |
| `10_overall_side_mechanism_cn.png` | 总装侧视机构简图 |
| `11_dof_kinematic_proof_cn.png` | 机构自由度与闭链成立性说明 |
| `12_motor_preload_latch_module_cn.png` | 电机预紧、锁止、释放模块图 |
| `13_jump_cycle_cn.png` | 蹲伏储能到腾空落地的运动过程 |
| `14_parts_layout_cn.png` | 零件布局与制造建议 |
| `15_robustness_validation_cn.png` | 鲁棒性检测矩阵 |
| `16_estimated_simulation_results_cn.png` | 预估仿真/能量计算结果 |
| `17_dimensioned_mechanism_cn.png` | 带尺寸的机构定义图 |
| `18_mechanism_motion_principle.gif` | 机构运动原理动图 |
| `20_dimensioned_mechanism_verified_cn.png` | 推荐使用的校核版尺寸机构图 |
| `21_verified_motion_envelope_cn.gif` | 校核版闭链运动动图 |
| `verified_body_and_links_import_to_inventor.dxf` | 推荐优先导入 Inventor 的校核版 DXF |
| `body_side_plate_import_to_inventor.dxf` | 机身侧板 DXF，可导入 Inventor |
| `leg_links_and_tail_import_to_inventor.dxf` | 连杆、尾杆 DXF，可导入 Inventor |
| `mechanism_schematic_import_to_inventor.dxf` | 机构简图 DXF |
| `BOM_redesigned_kangaroo_robot.csv` | 物料清单 |
| `design_dimensions.csv` | 关键尺寸表 |
| `estimated_jump_results.csv` | 预估跳跃性能数据 |

## 一句话设计逻辑

旧方案容易被认为只是外形模仿；新版方案强调功能仿生：后肢同步、弹性储能、快速释放、尾部平衡，并用 1 自由度闭链机构保证“机构确实成立、运动可控”。

## 建议提交方式

1. 把 `袋鼠仿生弹跳机器人_完整重设计报告.md` 整理成 Word/PDF。
2. 把 `10` 到 `18` 的图片/GIF 放进答辩 PPT 或报告。
3. 在 Inventor 中导入两个 DXF，按 `Inventor建模与装配指南.md` 建立零件与装配体。
4. 实物制作前先用纸板/亚克力快速验证闭链运动，再 3D 打印或激光切割正式件。

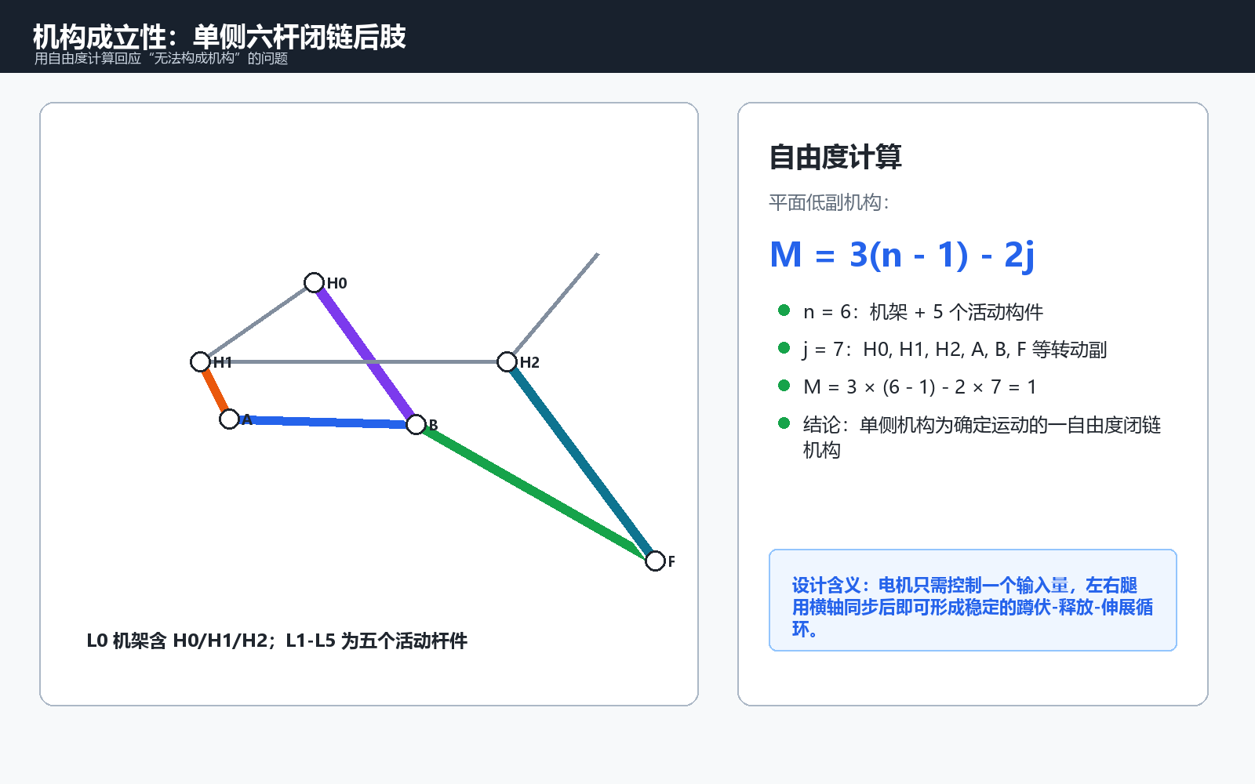
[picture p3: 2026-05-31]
11_dof_kinematic_proof_cn.png

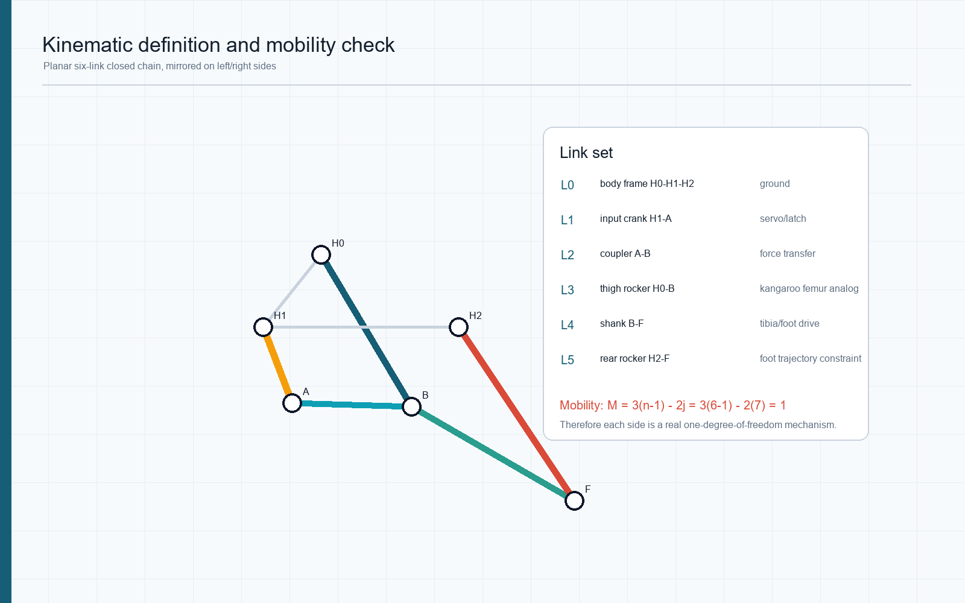
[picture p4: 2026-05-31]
02_kinematic_definition.png

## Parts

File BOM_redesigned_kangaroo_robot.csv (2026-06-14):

part | qty | material | manufacturing | notes
body_side_plate | 2 | 3-4mm PLA/Acrylic/carbon | 3D print or laser cut | fixed pivots H0/H1/H2/T + 4 corner standoff holes + winch mount
input_crank_H1_A | 2 | PLA/Aluminum | 3D print/CNC | 40 mm hole distance; 4 mm thick; pivot holes 3.4
coupler_A_B | 2 | PLA/Aluminum | 3D print/laser cut | 120 mm hole distance
thigh_rocker_H0_B | 2 | PLA/Acrylic | 3D print/laser cut | 100 mm hole distance
shank_B_F | 2 | PLA/Acrylic | 3D print/laser cut | 140 mm hole distance
rear_rocker_H2_F | 2 | PLA/Acrylic | 3D print/laser cut | 180 mm hole distance
foot_pad | 2 | TPU/rubber | 3D print/cast | Ø24x8 press-fit on foot tip; grip + landing damping
tail_rod | 1 | PLA/carbon rod | 3D print/standard rod | 180-220 mm adjustable
tail_mass | 1 | steel nuts | standard part | 0-30 g adjustable
winding_drum | 1 | PLA/Aluminum | 3D print/CNC | Ø36 bore Ø6.2 keys on motor shaft; rim catch tooth; tendon anchor
motor_clamp | 1 | PLA | 3D print | saddles Ø37 motor barrel; bolts to plate
release_pawl_latch | 1 | PLA/Aluminum | 3D print/CNC | 14deg self-locking pawl (servo release <1.5kg.cm); servo kicks tail; lip catches drum tooth
DC_gear_motor | 1 | standard | purchase | 37D 6-12V gear motor with Ø6 shaft; external winch
release_servo | 1 | standard | purchase | MG90S/20g servo flips the latch
battery_controller_pack | 1 | Li-ion + PLA tray | purchase | 2S Li-ion+ESP32+driver ~75g; mounts -Z to counter-balance the outboard winch
elastic_tendon | 2 | rubber/spring | purchase | extension spring or rubber band; drum->crank A
M3_bolt_80 | 6 | steel | purchase | pivot axles H0/H1/H2/A/B/F (head + nut retained)
M3_nut | 6 | steel | purchase | retains each pivot bolt
M3_axle_40 | 1 | steel | purchase | tail pivot at T
washer | many | nylon/PLA/steel | purchase/print | OD7 ID3.4 between every moving layer to reduce rub
standoff | 4 | brass/PLA | purchase/print | Ø8 x64 sets plate gap; stiffens frame
controller | 1 | Arduino/ESP32 | purchase | motor + servo control
motor_driver | 1 | TB6612FNG/BTS7960 | purchase | drives the preload motor
IMU | 1 | MPU6050 | purchase | pitch sensing for tail balance
limit_switch | 1 | standard | purchase | preload/full-wind detection
buck_converter | 1 | LM2596 | purchase | 5V rail for servo + logic
battery | 1 | 2S Li-ion/LiPo | purchase | power source

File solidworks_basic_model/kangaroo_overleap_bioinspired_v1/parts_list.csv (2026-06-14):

part_file | instances | role | key_dim_mm | material | manufacturing | notes
BodyPlate_Side.SLDPRT | 2 | frame side plate | ~315x154x3 | 3mm PLA/acrylic/carbon | 3D print or laser cut | v7: pivots H0/H1/H2/T + 4 standoff holes + lightening-hole field (~40% lighter)
L1_Crank_40.SLDPRT | 2 | input crank H1-A | 59.0 hole pitch x4 | PLA/aluminum | 3D print/CNC | v8: H1 end Ø10 623-bearing seat / A end Ø6 bushing seat
L2_Coupler_120.SLDPRT | 2 | coupler A-B | 108.9 hole pitch x4 | PLA/aluminum | 3D print/laser cut | v8: both ends Ø6 bushing seat
L3_Thigh_100.SLDPRT | 2 | thigh rocker H0-B | 88.2 hole pitch x4 | PLA/acrylic | 3D print/laser cut | v8: H0 end Ø10 623-bearing seat / B end Ø6 bushing seat
L4_Shank_140.SLDPRT | 2 | shank B-F | 100.3 hole pitch x4 | PLA/acrylic | 3D print/laser cut | v8: both ends Ø6 bushing seat
L5_Rocker_180.SLDPRT | 2 | rear rocker H2-F | 160.6 hole pitch x4 | PLA/acrylic | 3D print/laser cut | v8: H2 end Ø10 623-bearing seat / F end Ø6 bushing seat
Foot_80.SLDPRT | 2 | foot/toe link | 80 reach x4 | PLA | 3D print | v8: F end Ø6 bushing seat; tip takes press-fit FootPad
TailRod_210.SLDPRT | 1 | dual-mode tail rod (hinged at T) | 210 x H26 x4 | carbon/aluminum/PLA rod | standard rod/print | v11: pivots about root T; curved limit slot R28 +-18.25deg rides body stop pin -> swings between DOWN (tip on ground = 5th-leg support) and UP (lifted = hop counterbalance)
TailMass.SLDPRT | 1 | tail counterweight | Ø44 x16 bore3.4 | steel nuts/PLA | standard part | 0-30 g adjustable; disk stacked on +Z rod face + M3 pin through both
ElasticTendon_52.SLDPRT | 1 | elastic tendon | 52 working | rubber band/extension spring | purchase | energy-storage element drum anchor->crank A
Drum.SLDPRT | 1 | winding drum | r18 x26 bore6.2 | PLA/aluminum | 3D print/CNC | v8: keyed bore Ø6.2 + 2x1 keyway (GB/T 1096); 14deg back-raked ratchet tooth; tendon @r14
Motor.SLDPRT | 1 | DC gear motor (envelope) | Ø37 x L70 + Ø6 shaft | standard part | purchase | 37D gear motor; v8 Ø6 KEYED output shaft (GB/T 1096 keyway); external winch preload
MotorClamp.SLDPRT | 1 | motor saddle clamp | 48x60x12 bore37.4 | PLA | 3D print | saddles motor barrel; 2x M3 base holes to plate
Servo.SLDPRT | 1 | release servo (envelope) | 23x12x29 + flange | standard part | purchase | MG90S/20g; flange holes @+-14; output hub kicks the pawl
Latch.SLDPRT | 1 | release pawl | ~59x37x6 | PLA/aluminum | 3D print/CNC | L-pawl with 14deg self-locking lip (servo release <1.5kg.cm); pivot + tail + spring hole
M3_Bolt_80.SLDPRT | 7 | pivot + standoff bolt | M3 x80 SHCS | GB/T 70.1 steel 8.8 | purchase | 3 fixed pivots H0/H1/H2 + 4 corner standoffs; with spring+plain washer & nut
M3_Nut.SLDPRT | 7 | hex nut | M3 hex AF5.5 x2.4 | GB/T 6170 steel | purchase | retains each bolt; far side
M3_Axle_40.SLDPRT | 4 | tail-tip + bracket pins | Ø3 x40 | steel M3 | purchase | 1 tail-tip pin (rod tip + mass disk) + 3 on winch bracket (latch pivot + 2 servo flange)
M3_Axle_80.SLDPRT | 2 | full-width tail axles | Ø3 x80 | steel M3 | purchase | v11: tail root pivot at T (revolute) + body stop pin at TS that rides the tail limit slot
Washer.SLDPRT | many | anti-friction washer | OD7 ID3.4 x1 | nylon/PLA/steel | purchase/print | legacy inter-layer washer; superseded by sleeve bushings at A/B/F
Standoff_64.SLDPRT | 4 | plate standoff | Ø8 x64 bore3.2 | brass/PLA | purchase/print | sets 64mm plate gap; stiffens frame
BatteryPack.SLDPRT | 1 | battery+controller mass | 70x40x22 | purchase + PLA tray | purchase | 2S Li-ion+ESP32+driver; mounts -Z to counter-balance the outboard winch
FootPad.SLDPRT | 2 | foot grip/buffer | Ø24 x8 | TPU/rubber | 3D print/cast | press-fit on foot tip for grip + landing damping
WinchBracket.SLDPRT | 1 | outboard winch support plate | 94x64x4 bore-field | 3mm+ PLA | 3D print | carries latch pivot + servo flange + motor/drum bore; ties drive module to side plate via 3 posts
WinchPost_94.SLDPRT | 3 | winch standoff post | Ø8 x94 bore3.2 | brass/PLA | purchase/print | ties WinchBracket (z128) back to +Z side plate (z34); triangular layout (-88 | 74)(-2 | 74)(-45 | 108)
Bearing_623.SLDPRT | 6 | deep-groove ball bearing | d3 D10 B4 | GB/T 276 bearing steel | purchase | fixed pivots H0/H1/H2 (L+R); link hub turns on rolling elements about the fixed pin
Bushing_0604.SLDPRT | 16 | sleeve bushing | OD6 bore3.2 L4 | GB/T oil-impregnated bronze | purchase | moving pivots A/B/F; one per link hub; shared grooved pin runs through
Key_2x2x8.SLDPRT | 1 | flat key | b2 h2 L8 | GB/T 1096 steel | purchase | transmits winding torque drum<->motor Ø6 shaft via paired keyways
Circlip_E3.SLDPRT | 6 | E-ring circlip | for d3 shaft | GB/T 896 spring steel | purchase | axial retention of the 3 moving-pivot grooved pins (2 per pin)
SpringWasher_M3.SLDPRT | 7 | spring lock washer | M3 | GB/T 93 spring steel | purchase | anti-loosening under each pivot/standoff nut
Washer_M3.SLDPRT | 7 | plain washer | M3 OD7 t0.5 | GB/T 97 steel | purchase | spreads nut load on the plate
M3_GroovedAxle_80.SLDPRT | 3 | grooved pivot pin | Ø3 x80 + 2 grooves | steel | purchase/print | moving pivots A/B/F; links rotate on bushings; E-rings seat in the grooves

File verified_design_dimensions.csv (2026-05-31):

项目 | 数值 | 单位 | 说明
H0-H1 | 100 | mm | 校核版推荐尺寸
H0-H2 | 134 | mm | 校核版推荐尺寸
L1 曲柄 | 40 | mm | 校核版推荐尺寸
L2 连杆 | 120 | mm | 校核版推荐尺寸
L3 大腿摇杆 | 100 | mm | 校核版推荐尺寸
L4 小腿 | 140 | mm | 校核版推荐尺寸
L5 后摇杆 | 180 | mm | 校核版推荐尺寸
尾杆 | 180-220 | mm | 可调

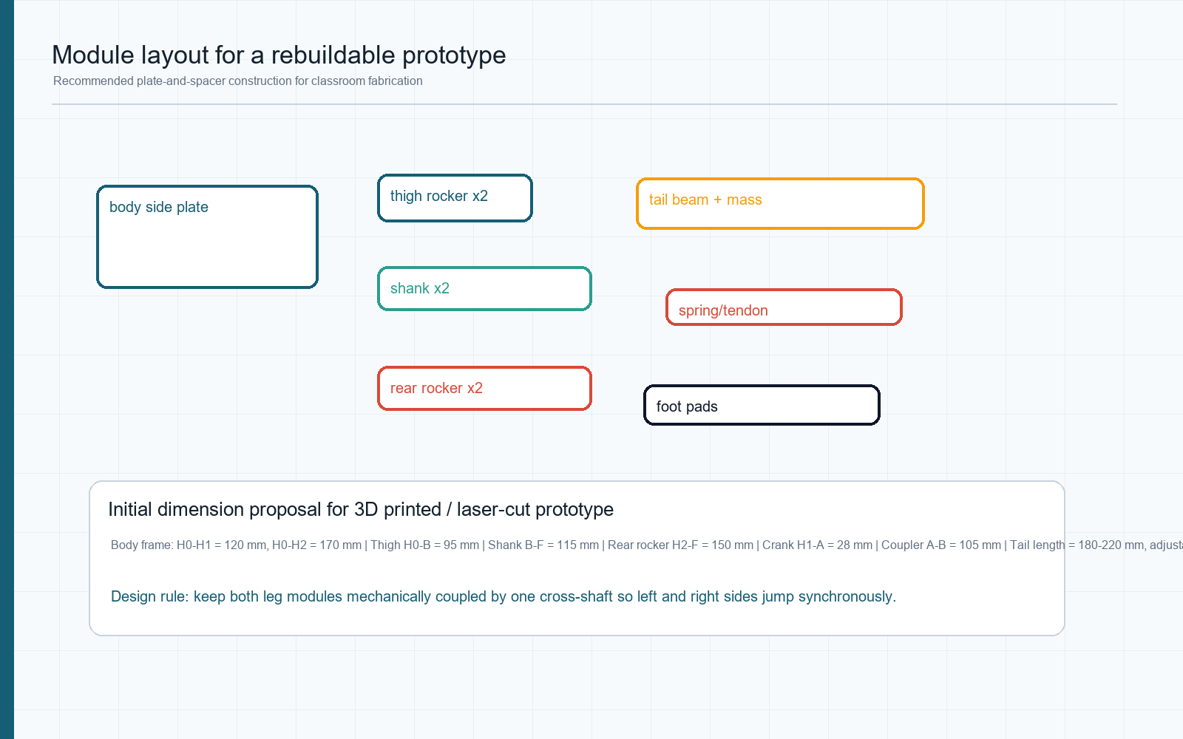
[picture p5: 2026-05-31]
04_parts_layout.png

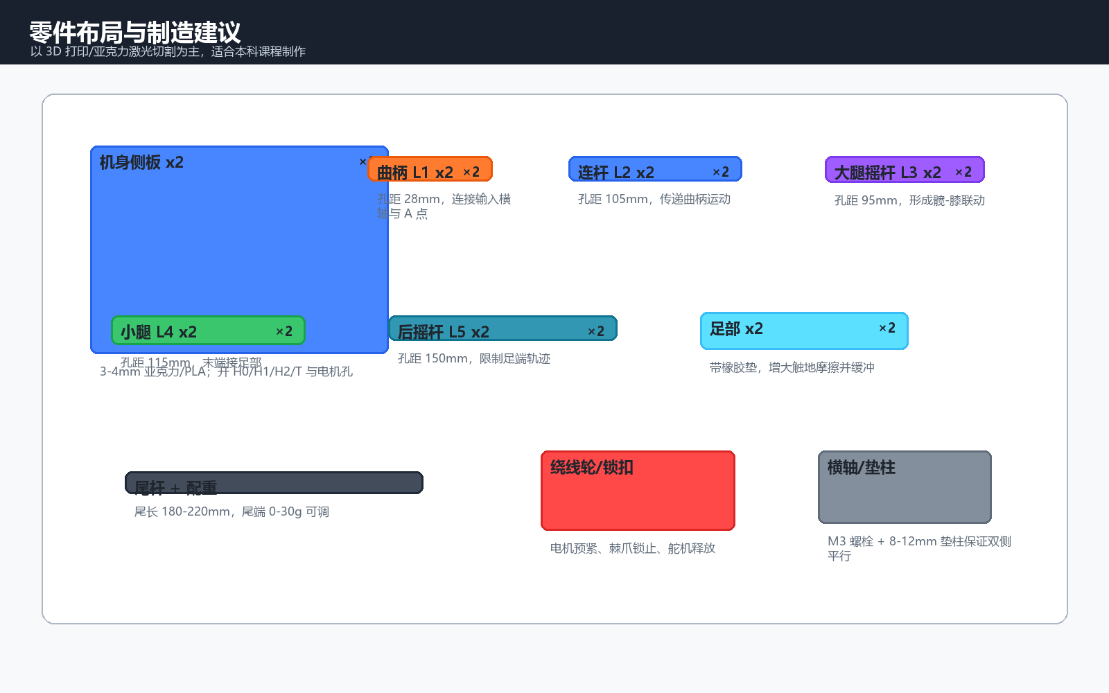
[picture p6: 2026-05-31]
14_parts_layout_cn.png

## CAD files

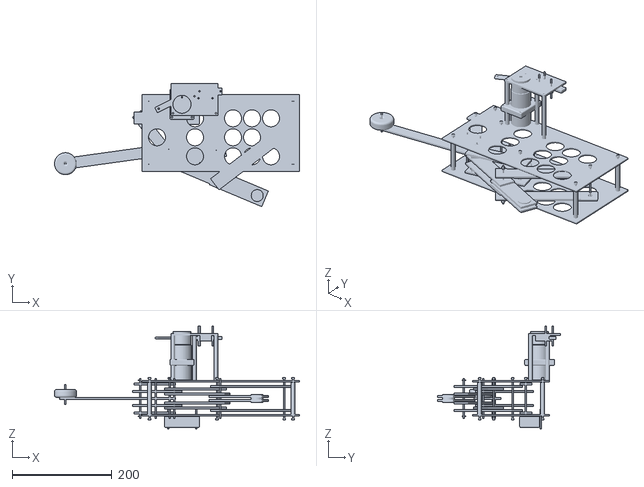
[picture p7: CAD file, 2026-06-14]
solidworks_basic_model/kangaroo_overleap_bioinspired_v1/assembly_export.STL
490.0 x 246.7 x 205.5

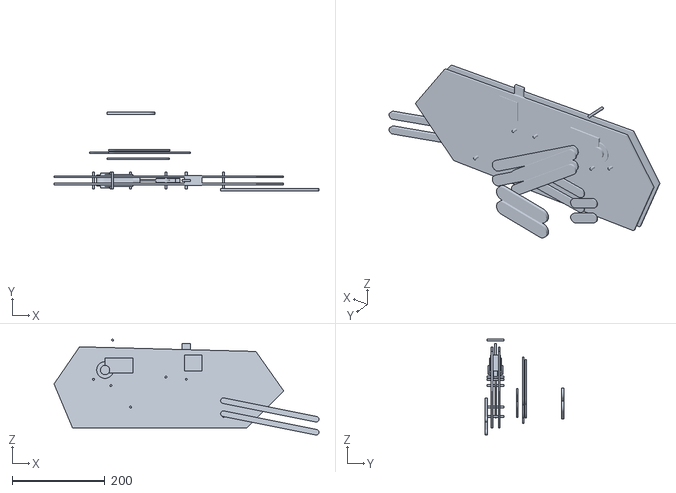
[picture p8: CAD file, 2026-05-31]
solidworks_basic_model/kangaroo_robot_basic_assembly.stl
571.0 x 170.6 x 206.8

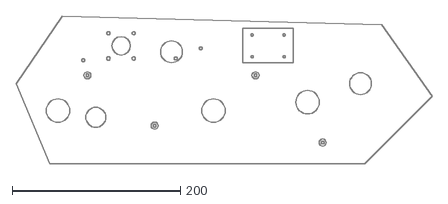
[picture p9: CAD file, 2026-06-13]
manufacturing_package/body_side_plate_manufacturing_v2.dxf
495.0 x 175.0

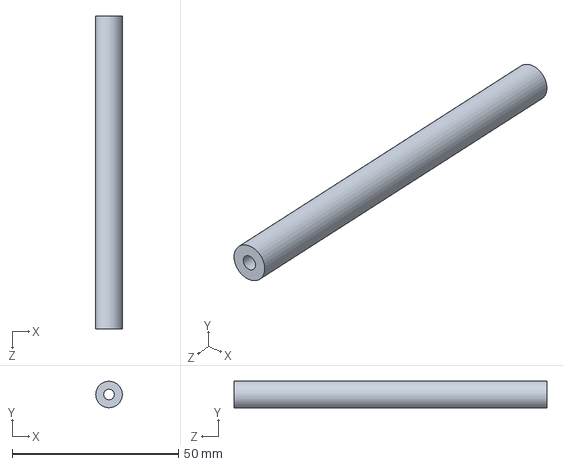
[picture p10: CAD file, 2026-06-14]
solidworks_basic_model/kangaroo_overleap_bioinspired_v1/parts/WinchPost_94.SLDPRT
8.00 x 7.99 x 94.0 mm

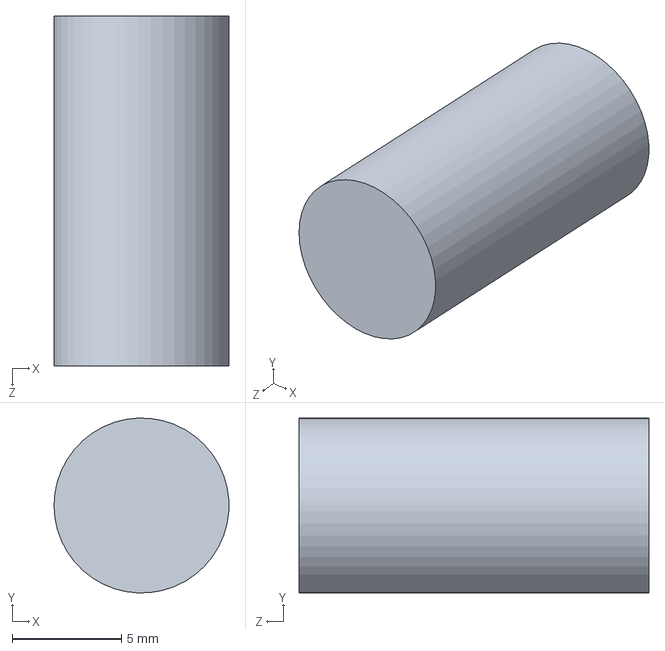
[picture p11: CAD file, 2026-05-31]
solidworks_basic_model/native_parts/Spacer_16mm.SLDPRT
8.00 x 8.00 x 16.0 mm

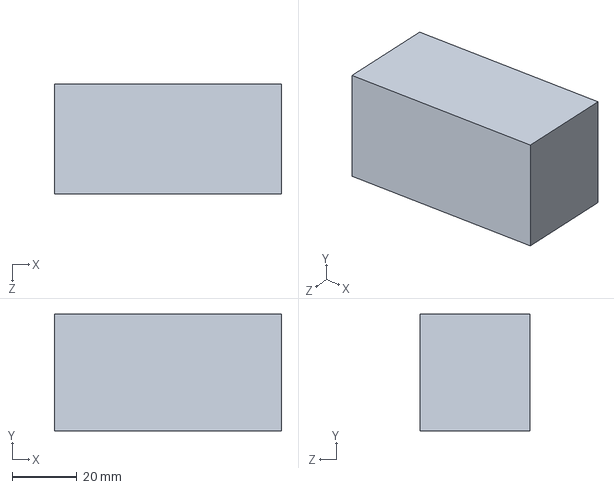
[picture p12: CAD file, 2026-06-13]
solidworks_basic_model/true3d_parts/Motor_3D.SLDPRT
70.0 x 36.0 x 34.0 mm

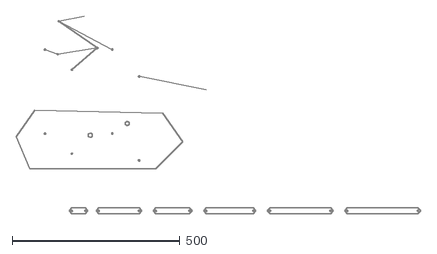
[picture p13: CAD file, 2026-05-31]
verified_body_and_links_import_to_inventor.dxf
1203.0 x 588.6

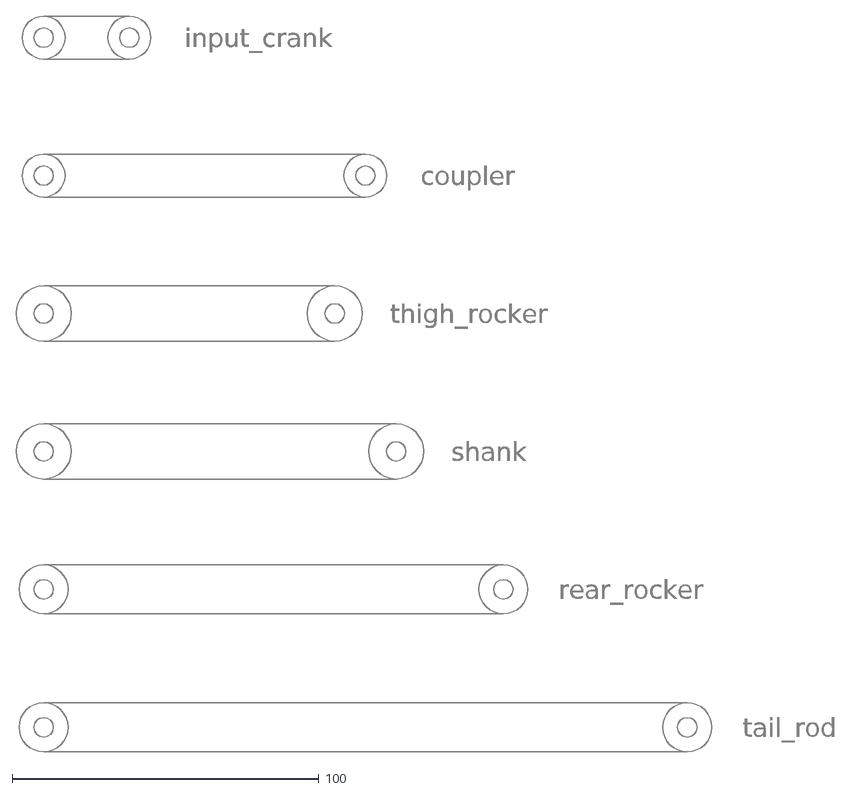
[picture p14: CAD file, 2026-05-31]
link_cutting_layout_import_to_inventor.dxf
input_crank
coupler
thigh_rocker
shank
rear_rocker
tail_rod

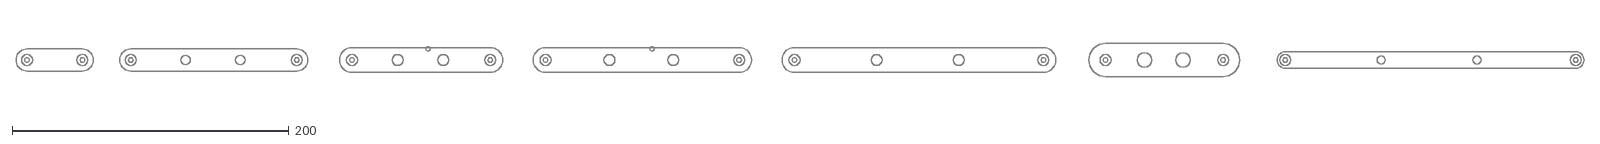
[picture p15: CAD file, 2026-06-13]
manufacturing_package/links_manufacturing_v2.dxf
1134.0 x 24.0

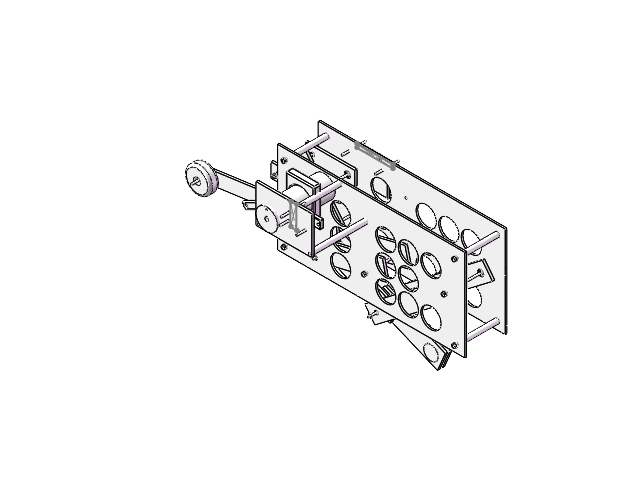
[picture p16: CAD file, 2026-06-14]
solidworks_basic_model/kangaroo_overleap_bioinspired_v1/Kangaroo_Overleap_BioInspired_Assembly.SLDASM
BodyPlate_Side x 2
Standoff_64 x 4
L1_Crank_40 x 2
L2_Coupler_120 x 2
L3_Thigh_100 x 2
L4_Shank_140 x 2
L5_Rocker_180 x 2
Foot_80 x 2
Bearing_623 x 6
Bushing_0604 x 16
TailRod_210
TailMass
M3_Axle_40 x 6
Motor
MotorClamp
Drum
Key_2x2x8
Latch
Servo
ElasticTendon_52
WinchBracket
WinchPost_94 x 3
BatteryPack
FootPad x 2
M3_Bolt_80 x 7
Washer_M3 x 7
SpringWasher_M3 x 7
M3_Nut x 7
M3_GroovedAxle_80 x 3
Circlip_E3 x 6
M3_Axle_80 x 2

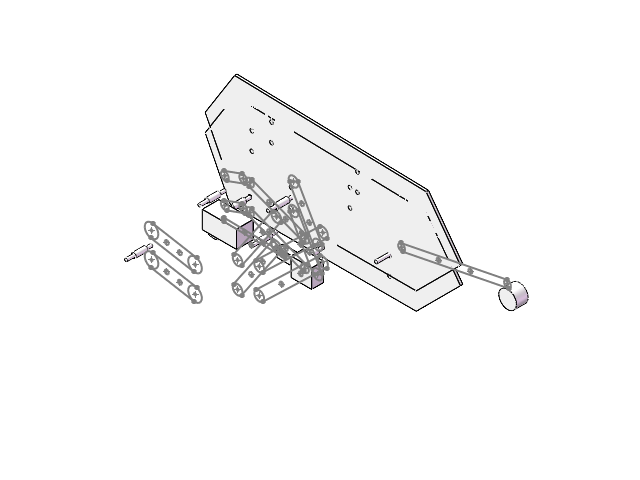
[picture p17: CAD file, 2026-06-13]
solidworks_basic_model/KangarooRobot_TRUE_3D_assembly.SLDASM
BodyPlate_3D x 2
L1_Crank_40_3D x 2
L2_Coupler_120_3D x 2
L3_Thigh_100_3D x 2
L4_Shank_140_3D x 2
L5_Rocker_180_3D x 2
Foot_90_3D x 2
TailRod_220_3D
TailMass_3D
ElasticTendon_3D
Motor_3D
Drum_3D
Servo_3D
Latch_3D
M3_Axle_52_3D x 7
Spacer_24_3D x 6

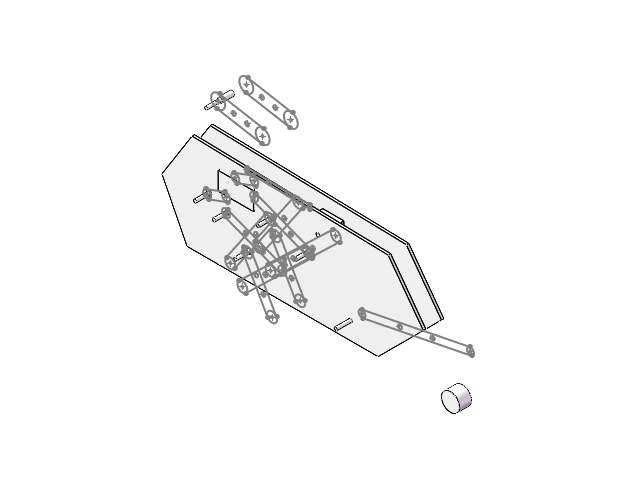
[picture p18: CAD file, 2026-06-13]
solidworks_basic_model/KangarooRobot_TRUE_3D_FIXED_assembly.SLDASM
BodyPlate_3D x 2
L1_Crank_40_3D x 2
L2_Coupler_120_3D x 2
L3_Thigh_100_3D x 2
L4_Shank_140_3D x 2
L5_Rocker_180_3D x 2
Foot_90_3D x 2
TailRod_220_3D
TailMass_3D
ElasticTendon_3D
Motor_3D
Drum_3D
Servo_3D
Latch_3D
M3_Axle_52_3D x 7
Spacer_24_3D x 6

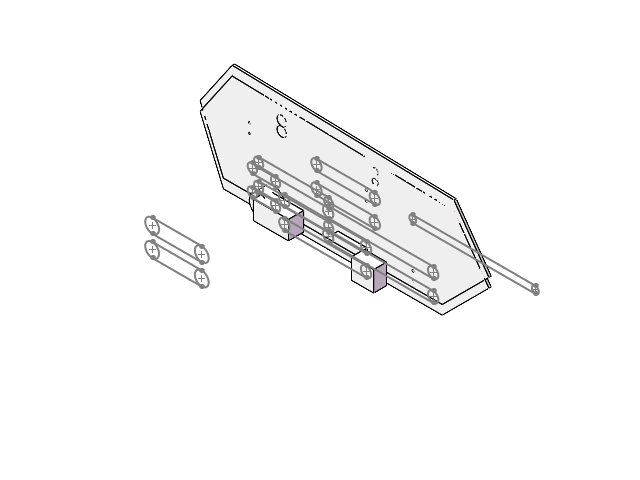
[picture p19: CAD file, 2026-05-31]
solidworks_basic_model/KangarooRobot_assembled_layout_v2.SLDASM
BodySidePlate_verified x 2
L1_Crank_40mm x 2
L2_Coupler_120mm x 2
L3_ThighRocker_100mm x 2
L4_Shank_140mm x 2
L5_RearRocker_180mm x 2
FootPad_85mm x 2
TailRod_210mm
WindingDrum_r18_w24
GearMotor_Placeholder_60x32x26
Servo_Placeholder_38x35x22
Latch_Placeholder_50x12x8

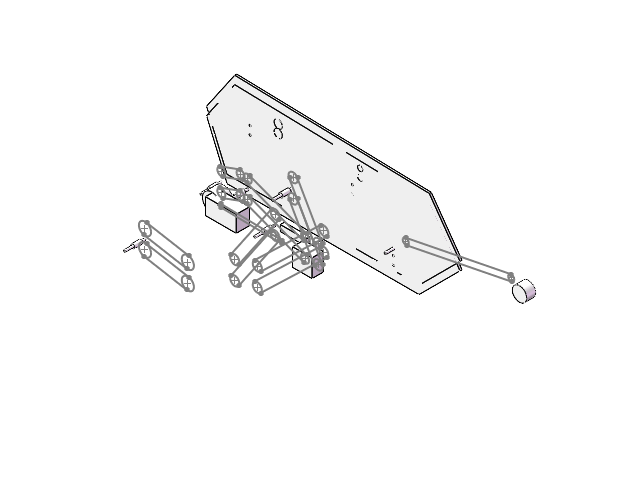
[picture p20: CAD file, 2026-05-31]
solidworks_basic_model/KangarooRobot_completed_engineering_layout.SLDASM
BodySidePlate_verified x 2
L1_Crank_40mm x 2
L2_Coupler_120mm x 2
L3_ThighRocker_100mm x 2
L4_Shank_140mm x 2
L5_RearRocker_180mm x 2
FootPad_85mm x 2
TailRod_210mm
TailMass_30g_placeholder
ElasticTendon_120mm
WindingDrum_r18_w24
GearMotor_Placeholder_60x32x26
Servo_Placeholder_38x35x22
Latch_Placeholder_50x12x8
M3_Axle_40mm x 7
Spacer_16mm x 6

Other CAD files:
solidworks_basic_model/overleap_reference_model/Overleap_reference_imported_assembly.SLDASM
solidworks_basic_model/probe_assembly.SLDASM
solidworks_basic_model/KangarooRobot_assembled_layout.SLDASM
solidworks_basic_model/KangarooRobot_basic_layout.SLDASM
body_side_plate_import_to_inventor.dxf
leg_links_and_tail_import_to_inventor.dxf
mechanism_schematic_import_to_inventor.dxf
solidworks_basic_model/L1_crank_H1_A_L.stl
solidworks_basic_model/L1_crank_H1_A_R.stl
solidworks_basic_model/L2_coupler_A_B_L.stl
solidworks_basic_model/L2_coupler_A_B_R.stl
solidworks_basic_model/L3_thigh_H0_B_L.stl
solidworks_basic_model/L3_thigh_H0_B_R.stl
solidworks_basic_model/L4_shank_B_F_L.stl
solidworks_basic_model/L4_shank_B_F_R.stl
solidworks_basic_model/L5_rear_rocker_H2_F_L.stl
solidworks_basic_model/L5_rear_rocker_H2_F_R.stl
solidworks_basic_model/axle_A.stl
solidworks_basic_model/axle_B.stl
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

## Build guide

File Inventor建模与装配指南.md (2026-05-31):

# Autodesk Inventor 建模与装配指南

本机未检测到完整 Autodesk Inventor 安装，仅发现 DWG TrueView。因此本项目交付 DXF 与建模步骤，便于在安装 Inventor 的电脑上打开并继续建模。

## 1. 建议文件结构

```text
KangarooJumpRobot/
  Parts/
    BodySidePlate.ipt
    L1_Crank.ipt
    L2_Coupler.ipt
    L3_ThighRocker.ipt
    L4_Shank.ipt
    L5_RearRocker.ipt
    Foot.ipt
    TailRod.ipt
    WindingDrum.ipt
    Latch.ipt
  Assembly/
    KangarooJumpRobot.iam
```

## 2. 导入 DXF

可导入文件：

- `body_side_plate_import_to_inventor.dxf`
- `leg_links_and_tail_import_to_inventor.dxf`
- `mechanism_schematic_import_to_inventor.dxf`
- `verified_body_and_links_import_to_inventor.dxf`：推荐优先使用的校核版 DXF

导入步骤：

1. 打开 Inventor，新建 `Standard(mm).ipt`。
2. 选择 `导入 CAD` 或在草图中插入 DXF。
3. 确认单位为 mm。
4. 对封闭轮廓执行 `拉伸`，侧板厚度取 3-4 mm，连杆厚度取 3 mm。
5. 对所有铰接孔使用 M3 clearance，建议直径 3.2 mm。

## 3. 零件建模建议

### 3.1 机身侧板

侧板包含固定孔：

| 孔位 | 功能 |
|---|---|
| H0 | 大腿摇杆固定铰点 |
| H1 | 输入曲柄固定铰点/横轴位置 |
| H2 | 后摇杆固定铰点 |
| T | 尾杆安装点 |
| motor | 减速电机安装区 |
| servo | 释放舵机安装区 |

建议：

- 左右侧板镜像使用。
- 侧板之间使用 8-12 mm 铜柱或打印垫柱连接。
- 机身前部留电池和控制板空间。

### 3.2 连杆

连杆孔距：

| 零件 | 孔距 |
|---|---:|
| L1 曲柄 | 40 mm |
| L2 连杆 | 120 mm |
| L3 大腿摇杆 | 100 mm |
| L4 小腿杆 | 140 mm |
| L5 后摇杆 | 180 mm |
| 尾杆 | 180-220 mm |

连杆两端建议做圆角，避免应力集中。若 3D 打印，孔附近加厚到 5-6 mm；若激光切割，孔边距离保持至少 6 mm。

### 3.3 绕线轮

建议参数：

- 外径：24-36 mm。
- 线槽宽度：3-5 mm。
- 中心孔：按电机轴直径建模，常见为 3 mm 或 D 型轴。
- 侧面加小孔用于固定线绳。

### 3.4 锁扣

锁扣可采用简单棘爪式：

- 一个固定在机身上的转动棘爪。
- 一个与曲柄或收线机构连接的卡槽。
- 舵机拨杆转动 20-40° 即可脱开。

课程样机不需要复杂加工，先用 PLA 打印锁扣，后续根据磨损换成铝片或钢片。

## 4. 装配约束

装配建议顺序：

1. 插入两片 `BodySidePlate.ipt`，用垫柱约束为平行侧板。
2. 插入 H1 输入横轴，左右曲柄固定在同一轴上。
3. 单侧依次装配 L1、L2、L3、L4、L5。
4. 复制或镜像另一侧机构。
5. 装配足部，保证左右足底在同一平面。
6. 装配尾杆与尾端配重。
7. 装配电机、绕线轮、弹性件和锁扣。

关键约束：

- 所有铰链用 `Insert` 或同轴约束。
- 左右曲柄使用同一根横轴，保证相位一致。
- 足部不应与机身侧板干涉。
- 弹性件两端不要穿过连杆或侧板。

## 5. 运动检查

在 Inventor 中可用以下方式检查：

- 手动拖动输入曲柄，观察全行程是否卡死。
- 打开接触集，检查足部和机身是否干涉。
- 使用驱动约束让 H1 曲柄转动 0-90°，观察 F 点轨迹。
- 若出现死点，优先调整 H2 位置或 L5 后摇杆长度。

## 6. 出图建议

课程报告至少建议输出：

- 总装侧视图。
- 单侧机构简图。
- 机身侧板工程图。
- 连杆工程图。
- 储能锁止模块局部放大图。
- BOM 表。

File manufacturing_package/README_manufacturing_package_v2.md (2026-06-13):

# Manufacturing Package v2

This package improves the practical buildability of the kangaroo-inspired jumping robot.

## Files

- `body_side_plate_manufacturing_v2.dxf`: body side plate with pivot holes, motor/servo mounting placeholders, tendon anchors, and lightening holes.
- `links_manufacturing_v2.dxf`: link cutting layout with M3 holes, bearing reference circles, lightening holes, and tendon hook points.
- `manufacturing_checklist.csv`: fabrication and assembly checklist.

## Important Practical Changes

1. Pivot holes now include both M3 clearance holes and bearing-clearance reference circles.
2. Body side plate includes motor, servo, and tendon anchor references.
3. Long links include lightening holes.
4. L3/L4 include tendon hook points for rubber band or extension spring attachment.
5. The package separates manufacturing DXF files from the earlier conceptual CAD files.

## Suggested Fabrication

- First prototype: 3 mm acrylic or 3D printed PLA.
- Stronger version: 2-3 mm aluminum links and 3-4 mm carbon/acrylic body plates.
- Pivots: M3 bolts with washers and locknuts.
- Optional bearings: select bearings first, then resize the bearing reference circles.

## Assembly Notes

- Keep left and right legs synchronized with a shared H1 input shaft.
- Add washers between links to avoid rubbing.
- Start elastic preload at 20 mm before testing larger preload values.
- Use a limit switch or current limit to prevent motor over-winding.
- Test tail masses at 0 g, 15 g, and 30 g.

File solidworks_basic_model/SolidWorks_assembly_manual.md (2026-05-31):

# SolidWorks Assembly Manual

The native part files are in:

`C:\Users\Gzj\Desktop\kangaroo_robot_redesign\solidworks_basic_model\native_parts`

The quick visual preview is:

`C:\Users\Gzj\Desktop\kangaroo_robot_redesign\solidworks_basic_model\kangaroo_robot_basic_assembly.stl`

## Recommended Assembly Steps

1. Open SolidWorks and create a new assembly.
2. Insert `BodySidePlate_verified.SLDPRT` twice. Place them at `Y = -8 mm` and `Y = +8 mm`.
3. Insert the five link parts twice, one set on each side.
4. Use concentric mates around the following joint points:
   - H0: `(0, 0)`
   - H1: `(-80, 60)`
   - H2: `(120, 60)`
   - A: approximately `(-42.4, 46.3)` in the shown pose
   - B: approximately `(45.0, 79.9)` in the shown pose
   - F: approximately `(-58.1, 231.0)` in the shown pose
   - T: `(200, -20)`
5. Insert the motor, drum, servo, and latch placeholder parts onto the body side plate.
6. Use the STL preview as a visual reference for the intended layout.

## Notes

- These parts are basic editable SolidWorks parts generated by API. They are intended as a first modeling base, not final manufacturing drawings.
- The current link parts are straight capsule links with M3 holes. Refine them later with fillets, lightening holes, bearing seats, and screw bosses.
- The body plate already contains the main pivot holes and approximate motor/servo mounting holes.
- For final mechanism animation, add mates manually and drive the H1 crank angle.

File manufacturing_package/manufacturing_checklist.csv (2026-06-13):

Item | Check | Target
Pivot holes | M3 clearance | 3.2-3.4 mm drill
Bearing option | micro bearing seat | outer diameter to match purchased bearing
Side plate spacing | left-right gap | 16-24 mm total with spacers
Link clearance | avoid plate rubbing | >= 0.5 mm each side
Elastic tendon | anchor hooks | no rubbing through full stroke
Latch | release direction | servo horn must clear latch in <45 deg
Tail | mass adjustability | 0/15/30 g test points
Foot | contact material | rubber pad bonded or screwed
Motor | winding direction | limit switch before over-stretch

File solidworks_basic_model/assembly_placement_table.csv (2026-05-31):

part | file | x_mm | y_mm | z_mm | notes
left body side plate | BodySidePlate_verified.SLDPRT | 0 | -8 | 0 | base side plate
right body side plate | BodySidePlate_verified.SLDPRT | 0 | 8 | 0 | mirror/use same part
left L1 crank | L1_Crank_40mm.SLDPRT | -80 | -18 | 60 | rotate to connect H1-A
right L1 crank | L1_Crank_40mm.SLDPRT | -80 | 18 | 60 | rotate to connect H1-A
left L2 coupler | L2_Coupler_120mm.SLDPRT | -43 | -18 | 46 | rotate to connect A-B
right L2 coupler | L2_Coupler_120mm.SLDPRT | -43 | 18 | 46 | rotate to connect A-B
left L3 thigh | L3_ThighRocker_100mm.SLDPRT | 0 | -18 | 0 | rotate to connect H0-B
right L3 thigh | L3_ThighRocker_100mm.SLDPRT | 0 | 18 | 0 | rotate to connect H0-B
left L4 shank | L4_Shank_140mm.SLDPRT | 45 | -18 | 80 | rotate to connect B-F
right L4 shank | L4_Shank_140mm.SLDPRT | 45 | 18 | 80 | rotate to connect B-F
left L5 rear rocker | L5_RearRocker_180mm.SLDPRT | 120 | -18 | 60 | rotate to connect H2-F
right L5 rear rocker | L5_RearRocker_180mm.SLDPRT | 120 | 18 | 60 | rotate to connect H2-F
left foot | FootPad_85mm.SLDPRT | -58 | -18 | 231 | connect at F
right foot | FootPad_85mm.SLDPRT | -58 | 18 | 231 | connect at F
tail rod | TailRod_210mm.SLDPRT | 200 | 0 | -20 | tail hinge point T
winding drum | WindingDrum_r18_w24.SLDPRT | -55 | 0 | 80 | motor preload spool
gear motor placeholder | GearMotor_Placeholder_60x32x26.SLDPRT | -25 | 0 | 90 | body-mounted motor
servo placeholder | Servo_Placeholder_38x35x22.SLDPRT | 135 | 0 | 95 | latch release servo
latch placeholder | Latch_Placeholder_50x12x8.SLDPRT | 80 | 0 | 72 | latch module

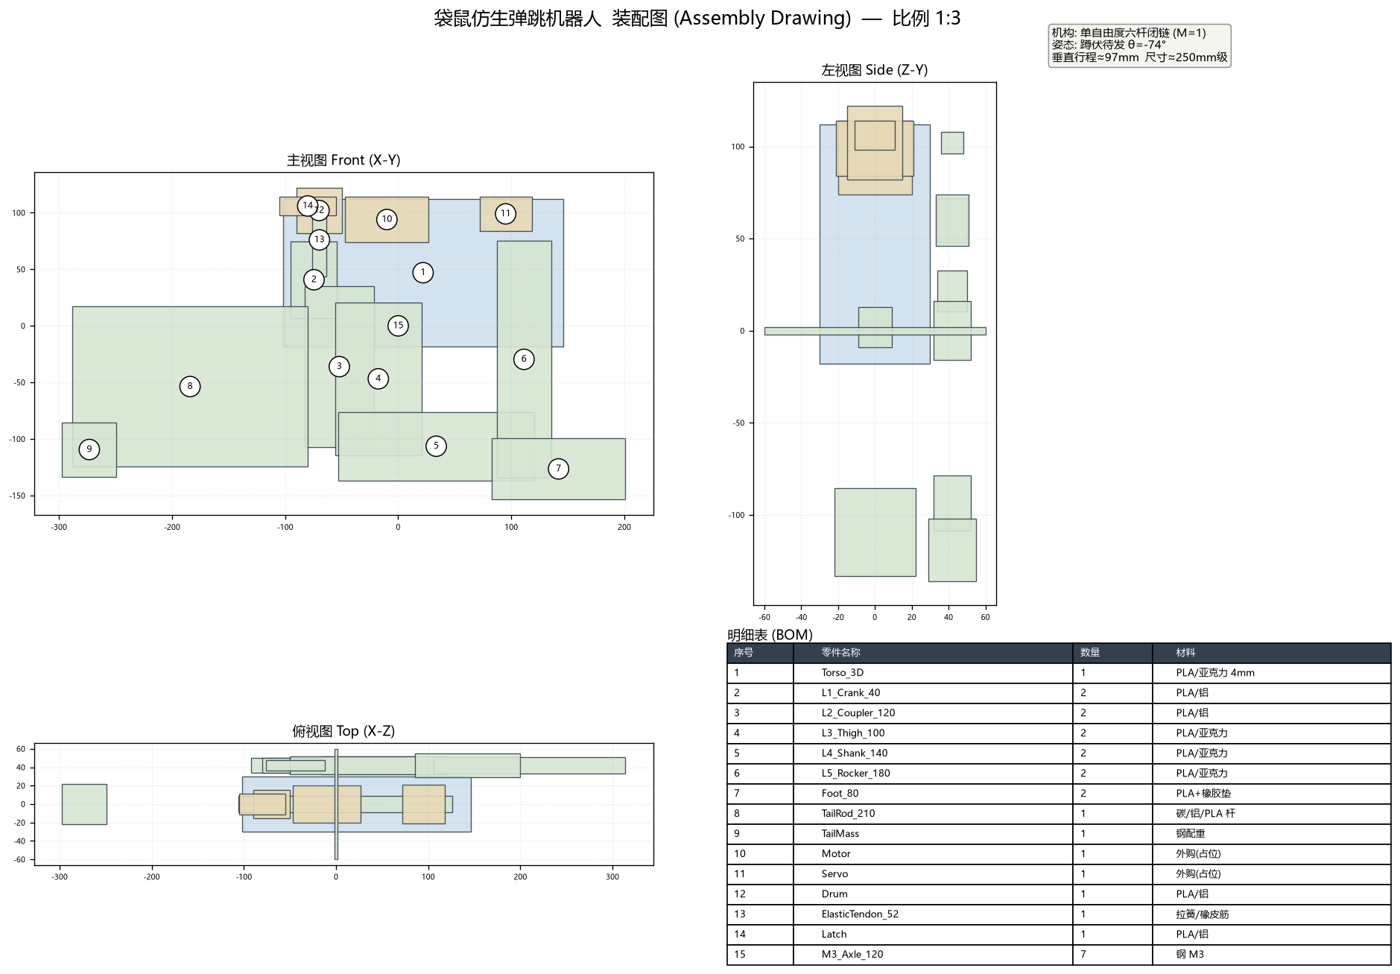
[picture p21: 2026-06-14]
solidworks_basic_model/kangaroo_overleap_bioinspired_v1/assembly_drawing.png

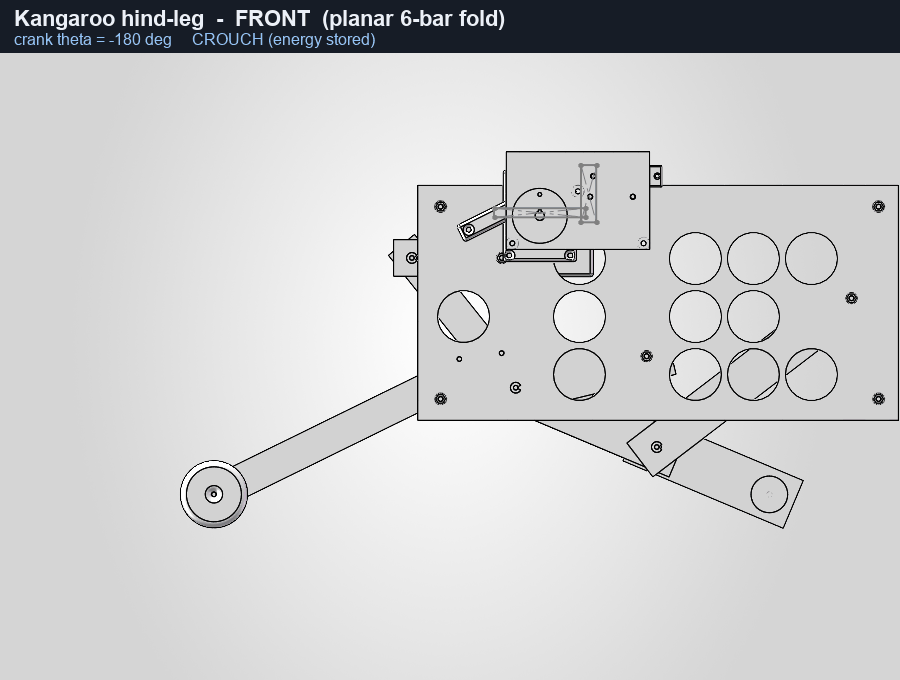
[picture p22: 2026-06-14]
solidworks_basic_model/kangaroo_overleap_bioinspired_v1/assembly_motion_front.gif

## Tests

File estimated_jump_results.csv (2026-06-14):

preload_mm | elastic_energy_J | estimated_height_cm | estimated_range_cm | assumptions
20 | 0.180 | 1.31 | 2.46 | m=0.63kg(实测预算),k=900N/m,eta=45%,launch_angle=35deg
25 | 0.281 | 2.05 | 3.85 | m=0.63kg,k=900N/m,eta=45%,launch_angle=35deg
30 | 0.405 | 2.95 | 5.54 | m=0.63kg,k=900N/m,eta=45%,launch_angle=35deg
35 | 0.551 | 4.01 | 7.54 | m=0.63kg,k=900N/m,eta=45%,launch_angle=35deg
40 | 0.720 | 5.24 | 9.85 | m=0.63kg,k=900N/m,eta=45%,launch_angle=35deg
45 | 0.911 | 6.63 | 12.47 | m=0.63kg,k=900N/m,eta=45%,launch_angle=35deg

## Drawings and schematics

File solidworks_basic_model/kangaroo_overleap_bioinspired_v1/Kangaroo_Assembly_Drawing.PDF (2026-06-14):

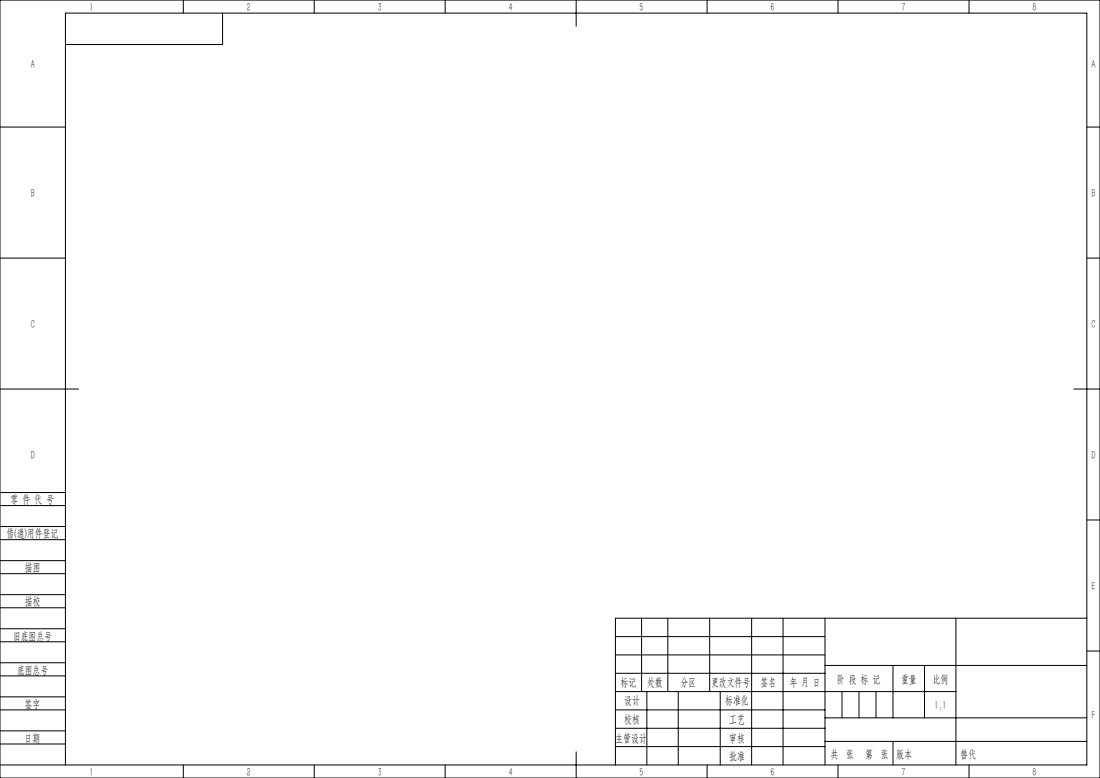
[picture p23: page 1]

标记 | 处数 | 分区 | 更改文件号 | 签名 | 年 月 日
设计 | | | 标准化 | | | | | 1:1
校核 | | | 工艺
主管设计 | | | 审核

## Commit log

2026-05-31 Initial kangaroo jumping robot redesign package
    [BOM_redesigned_kangaroo_robot.csv, BodySidePlate_verified.SLDPRT, ElasticTendon_120mm.SLDPRT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]
2026-06-03 Add workflow memory for CAD and GitHub delivery
2026-06-13 Improve CAD operability with manufacturing package
    [body_side_plate_manufacturing_v2.dxf, links_manufacturing_v2.dxf, manufacturing_checklist.csv]
2026-06-13 Add geometry-solved 3D SolidWorks assembly + course design specification
    - New trustworthy 3D assembly: kangaroo_overleap_bioinspired_v1
    - Geometry solved first (circle-circle intersection); all 5 link-length
    constraints satisfied to machine precision; foot sits below the body
    - 16 native SolidWorks parts, 31 instances, shared M3 axles + standoffs
    - Export bbox X~417 x Y~231 x Z~52 mm: true 3D body, not a flat plate
    - final_render.png + verify_multiview.png + assembly_export.STL
    - New course design task & specification document (12 sections, Chinese)
    - README updated; old flat assemblies marked historical/superseded
    - Overleap reference (MIT) and 28MB regenerable STL gitignored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
    [BodyPlate_3D.SLDPRT, Drum.SLDPRT, Drum_3D.SLDPRT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]
2026-06-14 Make kangaroo mechanism 1:1 printable: pinned linkage, standoff fix, full pipeline rerun
    - Printable parts/assembly: split BodyPlate into side plates with explicit
    corner holes (-118,-28)/(138,-28)/(-130,95)/(138,95), ≥13mm edge margin,
    clearing L1/L2 sweep
    - New standoffs (Standoff_64) and M3 axles (40/80); drop obsolete
    BodyPlate_3D, M3_Axle_60, Standoff_44
    - MateFix: concentric mates via face traversal (GetFaces + CylinderParams +
    component Transform2 + Entity.Select4), 21 mates ok
    - RenderColored: integer viewId + settle delay so 4 views render distinctly
    - CloseAll utility to release ~$ part locks before regeneration
    - Assembly drawing (PDF/SLDDRW), motion interference report,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
    [BodyPlate_3D.SLDPRT, BodyPlate_Side.SLDPRT, Drum.SLDPRT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]
2026-06-14 Add dual-mode biomimetic tail, fix multi-view animation, add experiment report
    Researched the kangaroo tail's real biomechanical role (ground-supporting
    5th leg in pentapedal walking; lifted counterbalance in hopping) and redesigned
    the previously fixed rigid tail into a hinged dual-mode mechanism: revolute
    root pivot at T with a curved limit slot (R28, +-18.25deg) riding a body stop
    pin, swinging between a DOWN (tip on ground) and UP (lifted) limit. Tail now
    swings in sync with the crank phase during the motion animation.
    Fixed the four-view animation bug where all viewpoints rendered identically
    (ShowNamedView2 with -1 silently no-ops; now passes swStandardViews IDs).
    Rebuild verified: 3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
    [BOM_redesigned_kangaroo_robot.csv, BatteryPack.SLDPRT, Bearing_623.SLDPRT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]
2026-06-14 Add dual-mode tail comparison images (crouch vs launch) for all 4 views
    The earlier static render PNGs predated the tail redesign and still showed
    the old fixed rigid tail, which is why the tail change wasn't visible in
    the still images. Generated fresh crouch-vs-launch comparison images from
    the current (hinged dual-mode tail) motion frames for front/iso/right/
    dimetric views so the tail swing is visible in stills, not just the GIFs.
2026-06-14 Re-export STL with new tail, regenerate drawing, add Word report
    The assembly_export.STL was stale (exported before the tail redesign) and had
    become a corrupt 80-byte file locked by a stuck SolidWorks process. Closed the
    process, re-exported a clean 3.5 MB STL (69524 triangles) from the current
    hinged dual-mode tail assembly. Regenerated the A3 assembly drawing so its views
    also show the new tail. Added a Word (.docx) version of the experiment report
    with the dual-mode tail comparison images and drawing preview embedded.
    [Kangaroo_Assembly_Drawing.SLDDRW, Kangaroo_Overleap_BioInspired_Assembly.SLDASM, assembly_export.STL]
